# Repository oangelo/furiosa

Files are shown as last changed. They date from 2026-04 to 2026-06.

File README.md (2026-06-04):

# Furiosa

Triciclo elétrico documentado em todos os detalhes.

## Especificações

| Item | Detalhe |
|---|---|
| Motor dianteiro | Hub motor Citycoco ~3 kW (sensorless FOC) |
| Motor traseiro | Motor com redução + diferencial (Hall) |
| Baterias | 2x 16S em paralelo: 8P (28Ah, BMS 100A) + 6P (21Ah, BMS 60A) |
| Células | EVE INR18650-35V (3500 mAh, 10.2A) |
| Controlador | 2x Flipsky FSESC 75200 (CAN bus) |
| Tensão | 60V nominal / 67.2V máx |
| Capacidade total | 49 Ah |
| Corrente máx. | ~140A contínuos / 100A prático (BMS menor) |
| Autonomia | _a definir_ |
| Velocidade máx. | _a definir_ |
| Peso total | _a definir_ |

## Estrutura do repositório

```
furiosa/
├── busbar/          # Sistema de conexão de alta amperagem
│   ├── busbar.md    # Documentação geral do sistema
│   └── bus-box/     # Caixa protetora da busbar
│       └── exports/ # Arquivos exportados (STEP, STL, etc.)
├── specs/           # Especificações técnicas detalhadas
├── maintenance/     # Histórico de manutenções e reparos
├── mods/            # Modificações e upgrades realizados
└── media/           # Fotos, vídeos e imagens
```

## Documentação

- [Sistema Busbar](busbar/)
- [Especificações Técnicas](specs/)
- [Histórico de Manutenção](maintenance/)
- [Modificações e Upgrades](mods/)
- [Mídia](media/)

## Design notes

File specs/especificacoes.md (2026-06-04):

# Especificações Técnicas

Documentação técnica completa do triciclo elétrico Furiosa.

---

## Motores

### Motor Dianteiro (Hub Motor Citycoco)

| Parâmetro | Valor |
|---|---|
| Tipo | Hub motor (roda dianteira) |
| Potência nominal | ~3 kW |
| Topologia | SPM (Surface Permanent Magnet) |
| Saliência magnética | Lq−Ld ≈ 6.41 µH (~6.6%) |
| Indutância | L = 97.31 µH |
| Flux linkage | 16.4 mWb (−10% do detectado) |
| Construção | Shaft fixo, roda gira em torno do eixo |

**Status do sensor Hall:**
- Hall 3: **Falha confirmada** (cabo partido na entrada do axle ou sensor defeituoso)
- Diagnóstico: duty cycle desequilibrado + glitches no plot `hall_analyze`

**Modo de operação:** Sensorless (FOC observer)

**HFI:** Testado e descartado — motor SPM não tem saliência suficiente, plot sem padrão senoidal

**Preset:** Heavy Inertial Load
- Openloop Lock Time: 0.5s
- Ramp Time: 0.5s
- Time: 0.20s
- Current Boost: 5A
- Current Max: 20A
- ERPM: 1500

### Motor Traseiro (Redução + Diferencial)

| Parâmetro | Valor |
|---|---|
| Tipo | Motor com redução e diferencial mecânico |
| Sensor Hall | Funcionando normalmente |
| Flux linkage | 21.6 mWb (−5% do detectado de 22.75 mWb) |
| Observer Gain | 80% do detectado |
| Inércia rotacional | Maior que o dianteiro (devido à redução) |

---

## Controladores (VESC)

### 2x Flipsky/Makerbase FSESC 75200

| Parâmetro | Valor |
|---|---|
| Firmware | VESC 5.2+ (upgrade disponível) |
| Tensão | 14-84V (4-20S) |
| Corrente contínua | 50V/200A; 75V/150A |
| Corrente de pico | 300A (burst) / 400A (máximo) |
| BEC | 5V @ 1A |
| Modos | DC, BLDC, FOC (sinusoidal) |
| Comunicação | USB, CAN, UART, SPI, IIC |
| Sensores | ABI, HALL, AS5047, AS5048A |
| ERPM máximo | 150.000 |
| PCB | Alumínio (dissipação térmica) |

### Configuração CAN Bus

| VESC | CAN ID | Motor | Função |
|---|---|---|---|
| Dianteiro | 95 | Hub motor Citycoco | Tração dianteira |
| Traseiro | 90 | Motor com redução | Tração traseira |

### Parâmetros de Corrente (por VESC)

| Parâmetro | Valor |
|---|---|
| Battery Max | 40A |
| Battery Regen | −12A |
| Motor Max | 90A |
| Motor Brake | −30 a −50A |
| Absolute Max | 150A |

### Controle

- **App:** ADC (throttle de punho)
- **Ré:** Botão no pino ADC (não PPM)
- **Controle:** Mestre (dianteiro) → CAN → Escravo (traseiro)

### Brake Chopper Externo

| Parâmetro | Valor |
|---|---|
| Comparador | LM393 |
| MOSFET | IRFP450 |
| Resistor de carga | 10Ω 100W |
| Função | Dissipar energia da frenagem regenerativa |

---

## Baterias

Duas baterias 16S ligadas em paralelo via busbar.

### Bateria 1 — 16S8P

| Parâmetro | Valor |
|---|---|
| Configuração | 16S8P |
| Capacidade | 28 Ah (3500 mAh × 8P) |
| Corrente máxima contínua | ~80A (10.2A/célula × 8P) |
| BMS | Daly Smart BMS 100A 16S |

### Bateria 2 — 16S6P

| Parâmetro | Valor |
|---|---|
| Configuração | 16S6P |
| Capacidade | 21 Ah (3500 mAh × 6P) |
| Corrente máxima contínua | ~60A (10.2A/célula × 6P) |
| BMS | Daly Smart BMS 60A 16S |

### Pack Combinado (Paralelo)

| Parâmetro | Valor |
|---|---|
| Configuração | 16S(8P+6P) = 16S14P |
| Tensão nominal | 60V |
| Tensão máxima | 67.2V (4.2V/célula) |
| Tensão mínima | 48.0V (3.0V/célula) |
| Capacidade total | 49 Ah |
| Corrente máxima contínua | ~140A |
| Corrente prática limite | 100A (limitado pelo BMS menor) |

### Células — EVE INR18650-35V

| Parâmetro | Valor |
|---|---|
| Química | NCM (Li-ion) |
| Tensão nominal | 3.65V |
| Capacidade nominal | 3500 mAh |
| Descarga contínua máx | 10.2A |
| Descarga de pico | 20A |
| Tensão carga máx | 4.2V |
| Tensão corte descarga | 2.5V |
| Peso | ~48g |
| Dimensões | 18.3mm × 65.0mm |

### BMS — Daly Smart BMS

| Parâmetro | Bateria 1 | Bateria 2 |
|---|---|---|
| Corrente contínua | 100A | 60A |
| Balanço | Passivo | Passivo |
| Comunicação | WiFi + CAN + Bluetooth | WiFi + CAN + Bluetooth |
| Monitoramento | App mobile "Smart BMS" | App mobile "Smart BMS" |

### Voltage Cutoffs (16S)

| Parâmetro | Valor | Por célula |
|---|---|---|
| Start (soft) | 51.20V | 3.20V |
| End (hard) | 48.00V | 3.00V |

### Construção

- Montagem DIY
- Células 18650 com solda de níquel
- Caixa metálica
- BMS com antena WiFi externa
- Termistores para monitoramento de temperatura

### Histórico de Problemas

- Queima de tira de níquel (corrente excessiva)
- Substituição de células em algum ponto
- BMS original queimou MOSFET de descarga → substituído pelo Daly 100A

---

## Proteção

### Fusíveis — Spintend Physical Fuse v01

2 unidades instaladas, uma por VESC, na linha positiva entre busbar e controlador.

| Parâmetro | Valor |
|---|---|
| Modelo | Spintend Physical Fuse v01 by Hohn |
| Configuração por unidade | 2× 60A em paralelo = 120A |
| Tensão máxima | 100V |
| Conectores | Amass XT90PW (macho/fêmea) |
| Curva de disparo (120A) | 100% In: >4h / 200% In: <60s |
| Posição | Linha positiva, entre busbar e VESC |

Ver documentação completa: [Sistema de Liga/Desliga](sistema-ligadesliga.md)

---

## Distribuição de Potência

| Componente | Função |
|---|---|
| Copper busbar | Ponto central de distribuição |
| Parafusos inox M6 | Conexão dos cabos |
| Caixa protetora (bus box) | Isolamento e proteção |
| Fusíveis Spintend 120A | Proteção por VESC (sobrecarga/curto) |

Ver documentação completa: [Sistema Busbar](../busbar/busbar.md)

---

## Sistema de Liga/Desliga

| Componente | Especificação |
|---|---|
| Relé principal | 12V, 200A |
| Conversor DC-DC | 20-90V → 12V |
| Chave switch | ON/OFF |
| Botão momentâneo | NO |
| Resistor pré-carga | Desconhecido (em paralelo com relé) |

Ver documentação completa: [Sistema de Liga/Desliga](sistema-ligadesliga.md)

---

## Transmissão

- **Dianteira:** Direta (hub motor)
- **Traseira:** Redução mecânica com diferencial

## Freios

- **Dianteiro:** _a definir_
- **Traseiro:** _a definir_

## Rodas / Pneus

- **Dianteira:** _a definir_
- **Traseiras:** _a definir_

## Dimensões e Peso

- **Comprimento:** _a definir_
- **Largura:** _a definir_
- **Altura:** _a definir_
- **Peso total:** _a definir_

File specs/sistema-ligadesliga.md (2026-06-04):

# Sistema de Liga/Desliga — Furiosa

## O Problema da Faísca

Os controladores VESC possuem capacitores de entrada grandes (~1000µF cada, ~2000µF total no sistema). Quando a bateria é conectada diretamente a capacitores descarregados, a diferença de potencial é máxima e a corrente de surto é limitada apenas pela resistência interna dos capacitores e da fiação — praticamente um curto-circuito momentâneo.

**Corrente de surto estimada:**
```
I = V / R_esr
I = 60V / ~0.05Ω = ~1200A (pico teórico)
```

Na prática a corrente é menor (limitada pela indutância e resistência dos cabos), mas o suficiente para:

- **Arco elétrico** no momento da conexão — degrada conectores e terminais
- **Vaporização de material** nos contatos —Connectores XT90 são projetados para 90A contínuos, não para picos de centenas de ampères
- **Risco de queimadura** se o conector estiver na mão
- **Danos ao BMS** — o surto passa pelo BMS antes de chegar aos capacitores

O problema é idêntico ao de ligar uma chave em um banco de capacitores — sempre que a tensão do capacitor é muito diferente da tensão da fonte, haverá um transiente de corrente proporcional à diferença.

## Anti-Spark Switches Comerciais

Existem switches anti-spark dedicados que resolvem o problema:

- **Flipsky Anti-Spark Switch** (~R$ 200-300)
- **MakerX Anti-Spark Switch** (~R$ 150-250)
- **Vedder Anti-Spark Switch** (open-source, ~R$ 100 em componentes)

Funcionam com um MOSFET que faz a pré-carga gradualmente e depois liga completamente. São compactos e plug-and-play.

**Problemas:**
- Preço elevado para o que fazem
- Limitados em corrente (tipicamente 100-200A)
- Componente adicional que pode falhar
- Difícil reposição no Brasil

## Solução Barata: Pré-Carga com Resistor

A ideia é simples: em vez de conectar a bateria diretamente aos capacitores, conectar primeiro através de um resistor que limita a corrente a um valor seguro. Depois que os capacitores carregam, curto-circuitar o resistor para operação normal.

**Cálculo da corrente de pré-carga:**
```
Com R = 15Ω:
I_inicial = 60V / 15Ω = 4A
P_inicial = 60V × 4A = 240W (por frações de segundo)
```

**Tempo de carga:**
```
τ = R × C = 15Ω × 0.002F = 0.03s
5τ (carga completa) = 0.15s
```

Os capacitores carregam em ~150ms — praticamente instantâneo para um ser humano. Depois disso, a tensão nos capacitores iguala a da bateria e não há mais diferença de potencial significativa.

**Componentes mínimos:**
- Resistor de 15Ω, 50W — suporta o pico de 240W por 150ms sem problemas
- Um meio de curto-circuitar o resistor após a carga (relé, chave manual, etc.)

---

## Sistema Atual

### Componentes Instalados

| Componente | Especificação |
|---|---|
| Relé principal | 12V, 200A |
| Conversor DC-DC | 20-90V → 12V |
| Resistor de pré-carga | Valor desconhecido (instalado em paralelo com o relé) |
| Chave switch | ON/OFF |
| Botão momentâneo | NO (normalmente aberto) |
| Fusíveis (2×) | Spintend Physical Fuse v01, 120A cada (2× 60A paralelo), 100V |

### Como Funciona

```
                         ┌─────────────────┐
  Bateria 60V ──────────┤ Resistor         ├───────── [Fusível 120A] ──► VESC dianteiro
              │          └─────────────────┘              │
              │              │                            │
              │    ┌─────────┴─────────┐         [Fusível 120A] ──► VESC traseiro
              └────┤ Relé 200A         ├─────────┘
                   │ (N.O.)            │
                   └───────┬───────────┘
                           │
                     bobina 12V
                           │
              ┌────────────┴────────────┐
              │                         │
        Chave ON/OFF              Botão N.O.
              │                    (momentâneo)
              │                         │
              └─────┬───────────────────┘
                    │
             Conversor DC-DC
              (60V → 12V)
                    │
                  GND
```
                        ┌─────────────────┐
  Bateria 60V ──────────┤ Resistor         ├──── VESCs (+)
              │          └─────────────────┘     │
              │              │                    │
              │    ┌─────────┴─────────┐         │
              └────┤ Relé 200A         ├─────────┘
                   │ (N.O.)            │
                   └───────┬───────────┘
                           │
                     bobina 12V
                           │
              ┌────────────┴────────────┐
              │                         │
        Chave ON/OFF              Botão N.O.
              │                    (momentâneo)
              │                         │
              └─────┬───────────────────┘
                    │
             Conversor DC-DC
              (60V → 12V)
                    │
                  GND
```

**Para ligar:**

1. Chave → ON
2. Corrente flui pelo resistor → carrega capacitores dos VESCs (sem faísca)
3. Conversor DC-DC gera 12V → energiza bobina do relé
4. Relé fecha → curto-circuita o resistor → conexão direta bateria↔VESCs
5. Sistema operacional

**Para desligar:**

1. Pressionar botão momentâneo → corta alimentação da bobina do relé
2. Relé abre → sistema desligado
3. A chave ON/OFF sozinha **não desliga** o sistema

### Problemas do Sistema Atual

1. **Resistor permanentemente no circuito** — embora a maioria da corrente passe pelo relé (resistência ~mΩ), o resistor em paralelo dissipa energia continuamente quando o relé está fechado
2. **Sequência de desligamento confusa** — a chave liga mas não desliga, é necessário usar o botão
3. **Se o botão falhar, não há como desligar** — a não ser desconectar a bateria
4. **Sem indicador visual** — impossível saber se o sistema está ligado ou desligado sem medição

---

## Melhorias Possíveis

### Opção A: Dois Relés (Pré-Carga Dedicada)

Adicionar um segundo relé (automotivo 12V 40A, ~R$ 15-25) dedicado exclusivamente à pré-carga. O resistor só fica no circuito durante os ~150ms de carga.

**Esquema proposto:**
```
  Bateria 60V ──────┬──────────────────────────────── VESCs (+)
                    │                                    │
          ┌─────────┴──────────┐                         │
          │ Relé Pré-Carga 40A ├──── Resistor 15Ω 50W ───┤
          │ (N.O.)             │                         │
          └─────────┬──────────┘                         │
                    │                                    │
          ┌─────────┴──────────┐                         │
          │ Relé Principal 200A ├────────────────────────┘
          │ (N.O.)             │
          └─────────┬──────────┘
                    │
              bobinas 12V
```

**Lógica de operação:**
1. Chave ON → pressiona botão → relé de pré-carga liga → capacitores carregam via resistor
2. Relé principal liga (manualmente ou com delay) → curto-circuita resistor
3. Solta botão → relé de pré-carga desliga → resistor fora do circuito
4. Relé principal permanece ligado (auto-retenção)
5. Chave OFF → corta alimentação → relé principal desliga → sistema off

**Vantagens:**
- Resistor fora do circuito durante operação normal
- Desligamento simples: basta a chave OFF
- Componentes baratos e fáceis de encontrar

**Desvantagens:**
- Mais fiação e complexidade
- Dois relés para gerenciar
- Necessita lógica de auto-retenção no relé principal

### Opção B: Chave Seletora (Manual)

Substituir o sistema de relés por uma chave seletora de 3 posições: OFF → PRÉ-CARGA → ON.

Na posição PRÉ-CARGA, a corrente passa pelo resistor. Na posição ON, a corrente passa direto. Sem eletrônica, sem relés.

**Vantagens:**
- Extremamente simples e robusto
- Sem eletrônica que pode falhar
- Operação intuitiva

**Desvantagens:**
- Precisa de uma chave de alta corrente (carregadora de bateria ou similar)
- Operação manual em dois passos
- Difícil encontrar chave adequada para 100A+ no Brasil

### Opção C: Anti-Spark Switch Comercial

Substituir todo o sistema por um anti-spark switch dedicado (ex: Flipsky, ~R$ 200-300).

**Vantagens:**
- Plug-and-play, sem projeto
- Compacto
- Pré-carga automática via MOSFET

**Desvantagens:**
- Caro
- Limitado em corrente
- Se queimar, é componente único sem reposição fácil

### Opção D: MOSFET com Pré-Carga (DIY)

Circuito com MOSFET de alta corrente (ex: IRFP4468) controlado por um RC para ramp de gate lenta, fazendo a pré-carga automaticamente.

**Vantagens:**
- Sem partes mecânicas (sem desgaste de contatos)
- Pré-carga automática e controlada
- Barato em componentes (~R$ 30-50)

**Desvantagens:**
- Complexidade eletrônica significativa
- Necessita dissipador grande
- Falha em MOSFET pode ser perigosa (curto permanente)
- Exige conhecimento de eletrônica de potência para projetar

### Comparação

| Critério | A: 2 Relés | B: Chave Seletora | C: Comercial | D: MOSFET DIY |
|----------|------------|-------------------|--------------|----------------|
| Custo | ~R$ 50 | ~R$ 30-80 | ~R$ 200-300 | ~R$ 30-50 |
| Complexidade | Média | Baixa | Baixa | Alta |
| Robustez | Alta | Muito alta | Média | Baixa |
| Desligamento simples | Sim | Sim | Sim | Sim |
| Reposição fácil | Sim | Sim | Não | Parcial |
| Sem resistor permanente | Sim | Sim | N/A | N/A |

---

## Referências

- [Especificações Técnicas Gerais](especificacoes.md)
- [Sistema Busbar](../busbar/busbar.md)

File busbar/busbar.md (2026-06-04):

# Sistema Busbar - Conexão de Alta Amperagem

## Descrição

Sistema de conexão elétrica de alta potência para o triciclo elétrico Furiosa. 
Consiste em uma barra de cobre com múltiplos terminais para conexão dos cabos de 
alimentação, protegida por uma caixa impressa em 3D.

## Componentes

### 1. Barra de Cobre

| Parâmetro | Valor |
|---|---|
| Material | Cobre eletrolítico |
| Espessura | 5 mm |
| Largura | 25 mm |
| Comprimento | ~50 mm (por segmento) |
| Quantidade | 3 segmentos |
| Acabamento | Furos e rosca M6 |

**Observações:**
- Barra cortada em pedaços de pouco menos de 50mm
- Furos roscados para fixação dos cabos
- Cobre por excelente condutividade elétrica

### 2. Fixação - Parafusos

| Parâmetro | Valor |
|---|---|
| Material | Aço inox |
| Tamanho | M6 |
| Quantidade | 3 por barra |
| Acabamento | Rosca completa |

**Por que inox?**
- Resistência à oxidação e corrosão
- Manutenção da condutividade ao longo do tempo
- Ideal para ambiente com vibração (veículo elétrico)

### 3. Porcas e Arruelas

| Componente | Especificação |
|---|---|
| Porcas | M6 auto-travantes com nylon |
| Arruelas | Inox M6 |

**Por que porcas com nylon?**
- Trava química que impede afrouxamento
- Resistente à vibração do veículo
- Não requer manutenção periódica de aperto

### 4. Caixa Protetora (Bus Box)

| Parâmetro | Valor |
|---|---|
| Material | _a definir_ (impressão 3D / usinagem) |
| Função | Proteção e isolamento da barra |
| Acesso | Tampa com parafusos |
| Status | Em desenvolvimento |

## Funcionamento

```
[ Bateria ] ──► [ Cabo ] ──► [ Busbar ] ──► [ Cabo ] ──► [ Controlador ]
                                    │
                                    ├──► [ Cabo ] ──► [ Motor ]
                                    │
                                    └──► [ Cabo ] ──► [ Acessórios ]
```

A barra de cobre serve como ponto central de distribuição da corrente, permitindo
múltiplas conexões de forma organizada e segura.

## Especificações Elétricas

| Parâmetro | Valor |
|---|---|
| Tensão nominal | 60V (16S Li-ion) |
| Tensão máxima | 67.2V |
| Corrente máxima | ~80A contínuos (limite das células) |
| Corrente prática | até 100A |
| Seção do cabo | _a definir_ |
| Tipo de conexão | Parafuso M6 com terminal olhal |

## Materiais Necessários

- [x] Barra de cobre 5x25mm
- [x] Parafusos inox M6 (9 unidades - 3 por barra)
- [x] Porcas auto-travantes M6 com nylon (9 unidades)
- [x] Arruelas inox M6 (9 unidades)
- [ ] Caixa protetora (em desenvolvimento)
- [ ] Cabos de alta corrente com terminais olhal M6

## Status do Projeto

**Em desenvolvimento (WIP)**

- [x] Definição da barra de cobre
- [x] Definição dos parafusos e fixações
- [x] Corte e preparação da barra
- [ ] Finalização da caixa protetora
- [ ] Testes de montagem
- [ ] Testes elétricos sob carga

## Notas de Desenvolvimento

- Barra de cobre cortada manualmente em segmentos de ~50mm
- Furos roscados M6 para fixação segura dos cabos
- Uso de inox em toda a fixação para evitar corrosão galvânica
- Porcas com nylon essenciais para ambiente com vibração

## Próximos Passos

1. Finalizar modelo 3D da caixa protetora
2. Imprimir/testar caixa
3. Definir seção e tipo dos cabos de conexão
4. Realizar testes de carga
5. Verificar aquecimento sob operação

## Arquivos Relacionados

- `busbar/bus-box/bus-box.FCStd` - Modelo FreeCAD da caixa (em desenvolvimento)
- `busbar/bus-box/exports/` - Arquivos exportados (STEP, STL, etc.)

## Referências

- [Especificações Técnicas](../specs/)
- [Modificações e Upgrades](../mods/)

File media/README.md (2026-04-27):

# Fotos

Adicione as fotos do triciclo nesta pasta.

Organize em subpastas se necessário, por exemplo:

- `fotos/gerais/` - Fotos gerais do triciclo
- `fotos/detalhes/` - Detalhes de componentes
- `fotos/modificacoes/` - Antes e depois de modificações

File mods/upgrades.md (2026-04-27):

# Modificações e Upgrades

Registro de todas as modificações e upgrades realizados.

| Data | Modificação | Motivo | Custo (R$) |
|---|---|---|---|
| _exemplo_ | _descrição da modificação_ | _motivo_ | _valor_ |

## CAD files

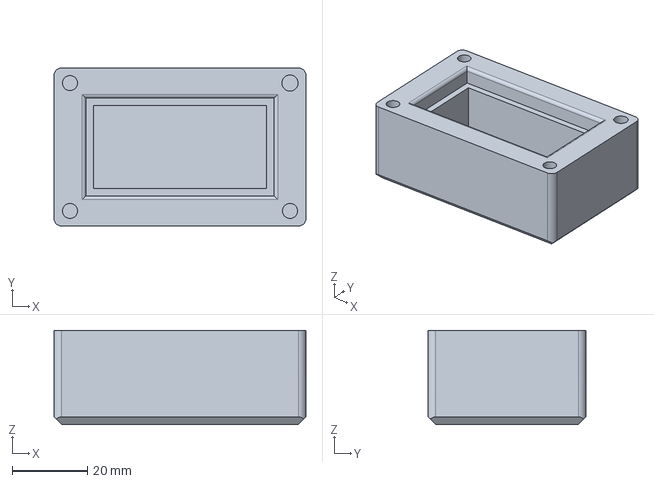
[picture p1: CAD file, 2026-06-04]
busbar/bus-box/bus-box.FCStd
67.0 x 42.0 x 25.0 mm

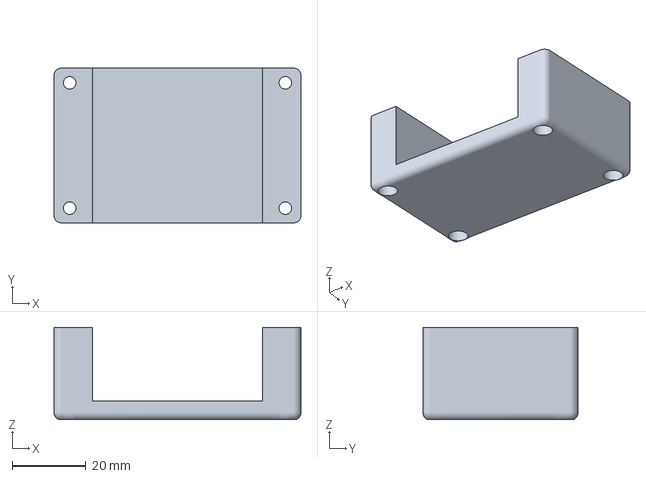
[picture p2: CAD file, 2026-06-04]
busbar/bus-box/exports/bus-box-tampa.3mf
67.0 x 42.0 x 25.0 mm

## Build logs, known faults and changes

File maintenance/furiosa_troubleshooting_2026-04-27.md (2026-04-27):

# Resumo da sessão de troubleshooting da Furiosa

## Ponto de partida

Você queria controlar o motor pelo VESC Tool e tinha um VESC dianteiro que não funcionava enquanto o traseiro rodava perfeitamente.

## Sequência do diagnóstico

**1. Controle pelo VESC Tool e interferência do ADC.** Descobrimos que o app ADC ativo sobrescreve os comandos da interface (setas, botões play/pause), mesmo via USB/CAN — bug conhecido no firmware. Solução: mudar temporariamente "App to Use" para "No App" durante testes pela interface. Você desativou o ADC e conseguiu testar livremente.

**2. Problema do VESC dianteiro — hipótese inicial: mosfet queimado?** O traseiro funcionava, o dianteiro não. Eu te dei o procedimento de teste de mosfets pelos fios de fase com multímetro em modo diodo, mas ressaltei que a 75200 tem 6 mosfets paralelos por fase, dificultando diagnóstico de mosfet individual.

**3. Refinamento do diagnóstico — não era mosfet.** Você descreveu o sintoma certo: "vibra loucamente mas não gira, sendo que na detection gira perfeitamente". Esse padrão exclui mosfet — detection roda em open-loop, então se uma fase estivesse comprometida, falharia ali. O problema estava no closed-loop (observer ou sensor).

**4. Investigação do hall sensor.** A tabela de hall do dianteiro estava numericamente correta (deltas de ~33 unidades, sequência monotônica), mas o motor vibrava com hall ativo. Você fez `hall_analyze` e o plot mostrou:
- Hall 3 com duty cycle absurdamente desbalanceado (ficava em 1 quase o tempo todo)
- Glitches impossíveis nos canais individuais
- Sequência caótica do "Combined"

Diagnóstico: hall sensor com problema elétrico — possivelmente sensor 3 com defeito, ou cabo de hall com mau contato/quebrado na entrada do eixo do hub motor.

**5. Tentativa de HFI como alternativa.** Medimos a saliência do motor: **L = 97,31 µH, Lq-Ld = 6,41 µH (~6,6%)**. Saliência marginal, típica de hub motor SPM (ímãs colados na superfície). Você ativou HFI e o plot mostrou ruído quase uniforme sem padrão senoidal — tracking inviável. **HFI descartado** para esse motor.

**6. Decisão: sensorless puro.** Você confirmou que sem hall, em modo sensorless, o motor da Furiosa funciona super forte. Diagnóstico fechado: VESC e motor estão íntegros, problema isolado ao hall sensor do dianteiro (mas você decidiu não abrir o motor).

**7. Tuning do open-loop pra melhorar a partida.** Aplicou o preset "Heavy Inertial Load" e ajustou parâmetros. Configuração final aceita:
- Openloop ERPM = 1500
- Openloop Hysteresis = 0,15 S
- Openloop Lock Time = 0,5 S
- Openloop Ramp Time = 0,5 S
- Openloop Time = 0,20 S
- Openloop Current Boost = 5 A
- Openloop Current Max = 20 A

**8. Problema do botão de ré.** O botão de ré não funcionava no modo "Current Reverse ADC2 Brake Button" — bug conhecido no firmware. Como teu manete é unidirecional (estilo moto), você precisava escolher entre regen variável e ré.

**9. Resolução final do botão de ré.** O problema real era o pino: você estava com **App to Use = "ADC and UART"** mas o botão estava conectado no pino que correspondia ao modo "ADC". Mudou para "ADC" puro e funcionou.

## Estado final da Furiosa

- **VESC traseiro:** modo Hall, funcionando perfeitamente.
- **VESC dianteiro:** modo Sensorless com tuning Heavy Inertial Load, partida aceitável.
- **Controle:** ADC com botão de ré funcionando, App to Use = "ADC".
- **Bateria 16S8P:** OK.
- **Pendência futura (sem urgência):** abrir o cubo do dianteiro um dia pra investigar o cabo de hall na entrada do eixo (ponto clássico de quebra por flexão). Se o sensor 3 estiver morto, troca por SS41 ou A3144 latching.

## Nota sobre o setup de conexão usado no diagnóstico

Durante esta sessão, o VESC Tool estava rodando no PC conectado via IP bridge a um celular, que por sua vez conectava ao VESC por Bluetooth. Segundo relatos no [fórum pev.dev](https://pev.dev/t/diagnosing-hall-sensors/1795/3), essa cadeia de conexão (Bluetooth + bridge) pode introduzir latência e ruído que comprometem ferramentas de diagnóstico como `hall_analyze`. O `hall_analyze` não rodou corretamente neste setup — possivelmente seria necessário conectar o cabo USB direto ao VESC para resultados confiáveis. Isso não invalida o diagnóstico de hall com defeito (os sintomas de vibração e os plots com glitches são consistentes), mas o resultado do `hall_analyze` deveria ser confirmado com conexão direta antes de conclusões definitivas sobre qual sensor está falhando.

## Aprendizados técnicos da sessão

- ADC ativo bloqueia controle pela interface do VESC Tool (mudar pra "No App" pra testar).
- Detection rodando bem + motor vibrando no controle = problema de sensor/observer, não de mosfet.
- Tabela de hall correta numericamente não garante hall funcional sob carga — sinal pode estar sujo, com glitches, ou intermitente.
- HFI exige saliência ≥15% pra funcionar bem; hub motor SPM raramente atende.
- O pino do botão de reverse depende do "App to Use" — erro comum trocar entre "ADC" e "ADC and UART" sem religar o botão no pino correto.
- Bug conhecido: "Current Reverse ADC2 Brake Button" ignora o botão de reverse no firmware atual.

## Para guardar

Salva o XML da config final do dianteiro como `furiosa_dianteiro_sensorless_2026-04-27.xml` e do traseiro como `furiosa_traseiro_hall_2026-04-27.xml`. Da próxima vez que mexer ou atualizar firmware, você tem o ponto de partida bom guardado.

Boa pilotada na Furiosa. 🏍️

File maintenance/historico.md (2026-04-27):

# Histórico de Manutenção

Registro de todas as manutenções realizadas na Furiosa.

| Data | Tipo | Descrição | Custo (R$) |
|---|---|---|---|
| abr/2026 | corretiva | Diagnóstico completo dos VESCs pós-desconexão de bateria. Re-flash firmware 6.06, investigação CAN, validação Flipsky 75200 Alu (operacional), Makerbase 75200 V2 OLD (CAN forwarding pendente). Ver [diagnóstico completo](furiosa_vesc_diagnostico_2026-04.md). | — |
| 27/abr/2026 | corretiva | Sessão de troubleshooting: hall sensor dianteiro com defeito (sensor 3), HFI descartado (saliência 6,6%), dianteiro migrado para sensorless com tuning Heavy Inertial Load. Botão de ré resolvido (App to Use = ADC). Ver [resumo completo](furiosa_troubleshooting_2026-04-27.md). | — |

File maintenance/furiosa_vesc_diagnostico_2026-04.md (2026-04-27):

# Furiosa — Diagnóstico e Configuração dos VESCs (abr/2026)

## Resumo executivo

Setup dual VESC do triciclo elétrico Furiosa após incidente de desconexão súbita
de bateria durante operação. Documenta processo de re-flash de firmware,
investigação de problemas de comunicação CAN entre as duas placas, configuração
master/slave, e estado funcional final.

**Status atual:**

- **Flipsky FSESC 75200 Alu (motor traseiro IPM, ID 90)** — operacional.
  Sustenta 80A de phase current a 95% duty sem aquecimento anormal.
- **Makerbase MKSESC 75200 V2 OLD (hub dianteiro SPM, ID 95)** — detecção de
  motor funciona e gira a roda em teste isolado, mas **não está recebendo
  comandos ADC via CAN do master**. Causa raiz não confirmada.
- **Investigação pendente:** testar se Makerbase responde a ADC direto na placa
  (sem CAN forwarding) para isolar dano de hardware vs. configuração.

## Hardware

### Placa 1 — Hub dianteiro

- **Modelo:** Makerbase MKSESC 75200 V2 (revisão antiga, anterior a 15/nov/2023).
- **Compra:** abril/2023, loja oficial Makerbase, R$ 528,18.
- **Hwconf na firmware:** `MKSESC_75200_V2_OLD`.
- **Característica de hardware:** low-side current sensing, **sem phase shunts**
  reais, **sem suporte a phase filtering**. Phase filter ligado nesta revisão
  pode danificar o ESC.
- **VESC ID no CAN:** 95.

### Placa 2 — Motor traseiro

- **Modelo:** Flipsky FSESC 75200 Aluminum PCB (versão original, anterior a Pro V2.0).
- **Hwconf na firmware:** `FSESC_75_200_ALU`.
- **Característica de hardware:** mesma topologia low-side, sem phase filter de
  hardware.
- **VESC ID no CAN:** 90.

### Motores

Resultados da Detection (firmware 6.06):

| Parâmetro | Hub dianteiro (Citycoco) | Motor traseiro (com diferencial) |
|---|---|---|
| Motor Current detectado | 94.48 A | 67.64 A |
| Motor R | 29.90 mΩ | 58.30 mΩ |
| Motor L | 96.32 µH | 161.15 µH |
| Motor Lq–Ld | 8.21 µH | **76.42 µH** |
| Motor Flux Linkage (λ) | 18.20 mWb | 22.75 mWb |
| Sensores | Hall | Hall |

**Interpretação:**

- **Hub dianteiro:** SPM clássico (Surface Permanent Magnet). Lq–Ld baixo
  indica rotor isotrópico. Sem reluctance torque significativo. MTPA dará
  ganho marginal.
- **Motor traseiro:** **IPM** (Interior Permanent Magnet) confirmado pela
  saliência alta (Lq–Ld = 76 µH). Tem reluctance torque disponível.
  **MTPA bem configurado pode trazer 10–15% de torque adicional por amp.**

## Bateria

- 16s8p EVE INR18650-35V.
- Histórico anterior: reparo de strip de níquel queimado (positivo).
- **Incidente recente:** desconexão súbita durante operação. Causa raiz da
  desconexão não documentada (BMS, conector, célula?).
- Implicação para os VESCs: spike de sobretensão de back-EMF + capacitância
  parasita pode ter estressado MOSFETs, capacitores eletrolíticos e
  transceivers CAN das duas placas.

## Histórico de firmware

### Origem do problema com firmware

Estas placas (Makerbase 75200 V2 e Flipsky 75200 Alu) foram lançadas com
firmware proprietária dos fabricantes que reportava `Hw: 75_300_R2` (incorreto).
Medições de corrente eram ruidosas, recursos como field weakening estavam
indisponíveis ou bugados. Não havia opção de update via VESC Tool oficial.

### Solução comunitária (2022)

- **jaykup** (esk8.news forum) compilou firmwares customizadas com hwconfs
  corretos (`FSESC_75_200_ALU`, `MKSESC_75_200_V2_OLD`) e disponibilizou
  como `.bin` para upload manual via VESC Tool.
- **casainho** (jan/2024) lançou release `VESCs_fix_noisy_currents-firmware_6.02`
  com filtro de corrente em software, melhorando significativamente a leitura
  ruidosa dos shunts low-side.

### Estado atual (2026)

- Os hwconfs `MKSESC_75_200_V2_OLD`, `MKSESC_75_200_V2`, `FSESC_75_200_ALU`
  estão **mergeados no upstream do Vedder** (`vedderb/bldc`) há tempos.
- Firmware é distribuída via VESC Tool em todas as releases atuais (6.06).
- O "manual change" descrito no tutorial original do jaykup hoje significa
  apenas **selecionar o hwconf correto uma vez** via "Show non-default
  firmwares", não baixar `.bin` de fórum.

### Fluxo de update aplicado

Para cada placa, uma única vez:

1. VESC Tool 6.06, conexão USB direta na placa.
2. Estado inicial: `Hw: 75_300_R2` (errado, mas é o que a fábrica configura).
3. **Firmware → Bootloader → Upload** (genérico).
4. **Firmware → Included Files → "Show non-default firmwares"**.
5. Seleciona o hwconf correto:
   - Makerbase (compra anterior a 15/nov/2023): `MKSESC_75200_V2_OLD`
   - Flipsky 75200 Alu (versão original): `FSESC_75_200_ALU`
6. Upload, reboot.
7. Confirma `HW_NAME` correto no Firmware tab após reboot.

A partir desse ponto, updates de versão (6.06 → 6.07 → ...) acontecem como
update normal — sem mais intervenção manual de hwconf.

### Critério crucial: phase filter

**Ambas as placas (Makerbase V2 OLD e Flipsky 75200 Alu) DEVEM ter
`Enable Phase Filters = False`** em Motor Settings → FOC → Filters.

Razão: nenhuma das duas tem phase shunts reais. Phase filtering em hardware
sem phase sensing é a queixa estrutural do pessoal técnico do esk8 forum
("phase filter joke"). Ligar pode danificar o ESC em ambas as gerações.

A Makerbase V2 nova (pós-Nov/2023) adicionou hardware para phase filter, mas
mantendo low-side sensing. A recomendação da comunidade veterana continua
sendo manter phase filter desligado mesmo na V2 nova.

## Configuração dual VESC via CAN

### Topologia adotada

- **Master:** Flipsky 75200 Alu (ID 90, motor traseiro). Lê ADC do throttle e
  replica comando via CAN para o slave.
- **Slave:** Makerbase 75200 V2 OLD (ID 95, hub dianteiro). Sem app de input
  ativo, apenas obedece comandos CAN do master.

### Configuração esperada — Master (Flipsky)

| Tab | Parâmetro | Valor |
|-----|---|---|
| App Settings → General | App to Use | ADC |
| App Settings → General → CAN | Controller ID | 90 |
| App Settings → General → CAN | CAN Baud Rate | 500k |
| App Settings → General → CAN | CAN Mode | VESC |
| App Settings → General → CAN | Send Status Over CAN | All |
| App Settings → General → CAN | Send CAN Status Rate Hz | 50 |
| App Settings → ADC → General | **Multiple ESCs Over CAN** | **TRUE** |
| App Settings → ADC → General | Control Type | (conforme throttle físico) |
| App Settings → ADC → General | Use Filter | True |

**Crítico:** o toggle **"Multiple ESCs Over CAN"** fica dentro da aba do app
ADC, **não** na aba CAN geral. Erro comum é configurar somente na aba CAN
geral e o forwarding do input não acontecer.

### Configuração esperada — Slave (Makerbase)

| Tab | Parâmetro | Valor |
|-----|---|---|
| App Settings → General | App to Use | **No App** |
| App Settings → General → CAN | Controller ID | 95 |
| App Settings → General → CAN | CAN Baud Rate | 500k |
| App Settings → General → CAN | CAN Mode | VESC |
| App Settings → General → CAN | Send Status Over CAN | All |

Slave não precisa de input próprio configurado. Status continua sendo enviado
via CAN para que o master possa monitorar (RT data, traction control).

### Tunagem inicial recomendada (não totalmente aplicada)

| Parâmetro | Hub Citycoco (ID 95) | IPM Traseiro (ID 90) |
|---|---|---|
| Flux Linkage detectado | 18.20 mWb | 22.75 mWb |
| Flux Linkage inicial sugerido | 16.4 mWb (–10%) | 21.6 mWb (–5%) |
| Observer Gain | 50% do detectado | 80% do detectado |
| Inductance (L) | manter detectado | manter detectado |
| Resistance (R) | manter detectado | manter detectado |
| MTPA | habilitar (ganho marginal) | **habilitar (ganho real)** |
| Field Weakening | 10–15A inicial | 10–20A inicial |
| Phase Filter | **False** (obrigatório) | **False** (obrigatório) |
| Sensor Mode | Hybrid | Hybrid |
| Sensorless ERPM threshold | 2000–3000 | 2000–3000 |

### Limites de corrente sugeridos

Considerando bateria 16s8p EVE INR18650-35V (capacidade nominal de pico ao
redor de 280A teóricos, mas conservativo para vida útil ~160–200A):

Por VESC, ponto de partida:

- **Motor (phase) max:** 80A em cada.
- **Battery max:** 50A em cada VESC, totalizando 100A de pack draw.
- **Battery min (regen):** −20A em cada, totalizando −40A regen.

Subir gradualmente após validação térmica e estabilidade de controle.

## Eventos e diagnóstico (cronológico)

### Incidente — desconexão de bateria sob carga

Bateria desconectou subitamente durante operação no triciclo. Causa raiz
exata não documentada. Possíveis riscos para os VESCs:

1. **Voltage spike de back-EMF + indutância parasita** — pode exceder breakdown
   dos MOSFETs (HYG015N10NS1TA, 100V).
2. **Loop de regen sem destino** — corrente regenerativa sem bateria como sink,
   capacitor de barramento absorve tudo, possível overvoltage.
3. **Faísca no reconnect** — inrush current alto se bateria reconectou com
   motor ainda em movimento.

### Resultado da Detection pós-incidente

Detection bem-sucedida em ambas as placas (resultado documentado acima).
Isso confirma:

- MCU funcional em ambas.
- USB e CAN físico operacionais para discovery.
- Pelo menos um par de gate drivers funcional por placa.
- Current sensing funcional nas três fases (caso contrário R, L, λ não seriam
  medidos coerentemente).
- Sensores Hall lidos corretamente.

**Detection NÃO testa:** MOSFETs sob alta corrente sustentada, capacitores
sob stress térmico, gate drivers degradados, sensores de Vbus descalibrados,
trilhas de PCB parcialmente danificadas.

### Sintoma 1 — "trancos estranhos" durante movimentação

Hub dianteiro apresentou movimento aos trancos. Hipóteses levantadas
(em ordem de probabilidade):

1. Tabela de Hall sensors não detectada/recalibrada após mudanças.
2. Ordem de fases vs. ordem de Halls inconsistente.
3. Sensor Mode em Sensorless puro em vez de Hybrid.
4. Openloop ruim na partida.

**Não totalmente investigado** antes da próxima descoberta.

### Sintoma 2 — Makerbase "sumindo" no CAN

Slave Makerbase desapareceu do dropdown de VESCs no VESC Tool durante
investigação dos trancos.

**Causa raiz identificada:** as duas VESCs estavam configuradas com o
**mesmo Controller ID**. Em CAN bus, IDs duplicados causam colisão de
pacotes e o VESC Tool não consegue distinguir as placas.

**Ação:** alterado um dos IDs para tornar único (95 e 90).

### Sintoma 3 — Comando manual de current via teclado não responde

Após config de IDs, descoberto que ADC funciona normalmente (motor gira
suavemente movendo o throttle), mas comando manual de "set current" via
teclado/slider do VESC Tool não faz o motor girar mesmo com valores altos.

**Hipótese provável:** comandos manuais de "Set Current" via VESC Tool têm
**timeout interno de ~1 segundo** — se não reenviado dentro do timeout, o
controle volta para zero. Comandos via app (ADC) são contínuos por design.

**Hipótese secundária:** valores baixos (5–10A) podem estar abaixo do
threshold de atrito estático do hub motor parado, que precisa tipicamente
de 15–25A para iniciar rotação.

**Não-bloqueador para operação real** — ADC funcionando é o caminho
operacional desejado.

### Sintoma 4 (atual) — Slave Makerbase não responde a comandos via CAN forwarding

Estado atual após todas as configurações acima:

- Master (Flipsky) recebe ADC e gira motor traseiro normalmente.
- Slave (Makerbase) aparece no scan CAN, Detection roda com sucesso, motor
  gira em testes isolados.
- Quando master está acelerando via ADC, **slave permanece parado**.
- Não confirmado se Iq do slave está chegando a zero (comando não
  propagou) ou está com valor mas sem efeito (problema de execução
  no slave).

**Investigação pendente:**

1. Conectar ADC direto na Makerbase (sem CAN) para testar se input físico
   gira o motor isoladamente. Se sim → problema é específico de CAN
   forwarding. Se não → problema é mais profundo no slave.
2. Verificar Iq, Duty Cycle e Current Setpoint do slave em RT Data
   simultâneo enquanto master comanda.
3. Testar comando direto via terminal do master:
   `fwd_can 95 motor_current` (ou sintaxe equivalente).
4. Substituir cabo CAN por outro para descartar mau contato físico.
5. Medir resistência entre CAN_H e CAN_L com tudo desligado:
   - Esperado: ~60Ω (dois terminadores de 120Ω em paralelo).
   - 120Ω: faltou um terminador.
   - Infinito: faltam ambos.
6. Wipe Configuration completo das duas placas e reconfigurar do zero.

## Status operacional validado

### Flipsky 75200 Alu — APROVADO para operação

Teste de carga sustentado:

- Throttle aplicado via ADC.
- Sustentou **80A de phase current a 95% duty cycle**.
- **Sem aquecimento anormal**.
- **Sem fault** durante o teste.

Indica MOSFETs, gate drivers, current sensing e dissipação térmica em
condição operacional pós-incidente. Placa pode ser considerada saudável.

### Makerbase 75200 V2 OLD — STATUS PARCIAL

- Detection: OK.
- Motor gira em teste isolado (movimento mostrado).
- **Não responde a comandos do master via CAN forwarding** (causa raiz
  pendente).
- Saúde de hardware sob carga sustentada **não validada** (testes de carga
  progressiva não realizados isoladamente nesta placa).

## Próximos passos

### Curto prazo (diagnóstico)

1. **Conectar ADC direto na Makerbase** e testar se input físico gira o motor.
   Resultado isola se problema é só CAN forwarding ou mais profundo.
2. **RT Data simultâneo** das duas placas durante operação ADC do master.
   Olhar Iq, Duty Cycle, Current Setpoint do slave.
3. **Substituir cabo CAN** por cabo de teste novo.
4. **Multímetro** entre CAN_H e CAN_L (tudo desligado): esperado ~60Ω.
5. **Wipe + reconfigure** se nada acima resolver.

### Médio prazo (validação completa)

1. Teste de carga progressiva (20A → 40A → 60A → 80A) na Makerbase
   isoladamente, mesmo padrão validado na Flipsky.
2. Teste de regen estático (`foc_openloop 30 3000` seguido de
   `foc_openloop -20 3000`) em ambas para validar tolerância a regen
   pós-incidente.
3. Logging metr.at em trajeto curto real para detectar assimetrias
   (temperatura, corrente, RPM, regen).

### Longo prazo (decisão de upgrade)

Se confirmado dano persistente na Makerbase ou problema irreparável de CAN:

| Opção | Custo aprox. (BR) | Ganho real |
|---|---|---|
| MKSESC 75200 V2 OLD usado | ~R$ 400–500 | Lateral, mesmo problema potencial |
| MKSESC 75200 V2 nova (pós-Nov/2023) | ~R$ 600 | Marginal |
| **MKSESC 84200HP** (INA241, phase shunts reais) | **~R$ 700–1200** | **Significativo: resolve estruturalmente o ruído de current sensing** |
| Spintend UBOX V2 75V | ~R$ 700–1000 | Lateral |
| Trampa VESC 75/300 | R$ 2500+ | Excelente, overkill |

**Recomendação se for trocar:** Makerbase 84200HP. Resolve estruturalmente
o problema original de leitura de corrente que motivou todo o histórico
de firmware customizada (jaykup, casainho). Mantém compatibilidade de
tensão (84V = 16s full charge). Permite usar phase filter corretamente.
MTPA mais efetivo no motor traseiro IPM.

Decisão recomendada de escopo:

- Substituição de UMA placa (R$ ~900): mantém setup heterogêneo, requer
  tuning separado das duas.
- Substituição de AMBAS (R$ ~1800): setup simétrico, fácil de tunar,
  Makerbase V2 OLD e Flipsky Alu antigas viram peças para Maldita ou
  Gárgula.

## Observações técnicas relevantes

### Sobre a "vadicus strategy"

Para hub motors grandes que apresentam ABS overcurrent ou cogging em
baixa rotação, a abordagem documentada no esk8 forum recomenda:

- Reduzir Observer Gain para 30–50% do valor detectado.
- Reduzir Flux Linkage em 10–15% do detectado.
- Subir `Slow ABS Current Limit` para True (usa magnitude vetorial em vez
  de shunt individual, mais robusto a ruído).
- Aumentar `Max Absolute Current` 20–30% acima do `Motor Max` configurado.

### Sobre detection com dual VESC

**Sempre rodar Motor Detection com apenas uma VESC ativa por vez.**
Há relatos no fórum de placas danificadas por detection paralela em CAN
bus simultâneo. Desconectar fisicamente o motor da outra VESC durante
detection é a prática recomendada.

### Sobre CAN forwarding e timeout

Comandos enviados via CAN têm timeout de ~1 segundo no receptor. O master
deve enviar comandos em frequência maior que isso (50 Hz padrão).
Send CAN Status Rate baixo demais (1–5 Hz) causa o slave receber comando,
expirar, voltar a zero, receber próximo, expirar novamente — comportamento
"engata-larga" indistinguível de problema de hardware.

### Sobre IDs CAN duplicados

VESC Tool não detecta IDs duplicados de forma explícita. Sintoma é placa
"sumir" intermitentemente do dropdown ou comportamento errático no
forwarding. Sempre verificar manualmente que IDs são únicos quando
configurar dual ou multi-VESC.

## Referências

- Tópico original do jaykup no esk8.news:
  <https://forum.esk8.news/t/how-to-update-firmware-on-the-flipsky-75100-75200-foc-esc/61819>
- Release do casainho com filtro de corrente:
  <https://github.com/casainho/bldc/releases> (tag
  `VESCs_fix_noisy_currents-firmware_6.02`)
- Wiki da Makerbase (desatualizada, escrita em 2022):
  <https://github.com/makerbase-mks/VESC-MKS/wiki/Makerbase-VESC75-Series-Upgrade-Instructions>
- Hwconf MKSESC_75_200_V2_OLD no upstream do Vedder:
  <https://github.com/vedderb/bldc/blob/master/hwconf/makerbase/75_200_V2/hw_mksesc_75_200_v2_old.h>
- Archive de firmwares compiladas históricas:
  <https://github.com/vedderb/vesc_fw_archive>

---

*Documento gerado em abril/2026 como registro técnico do projeto Furiosa
para o repositório no GitHub.*

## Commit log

2026-04-27 Adiciona diagnóstico VESC abr/2026 e registra no histórico de manutenção
2026-04-27 Adiciona resumo da sessão de troubleshooting 27/abr/2026
2026-05-29 chore: renomear arquivo FreeCAD para usar hifens
    [caixa-conexao-alta-amperagem.FCStd]
2026-05-29 docs: adicionar documentacao da caixa de conexao de alta amperagem
2026-05-29 refactor: padronizar nomes de arquivos e pastas
    - Renomear pastas: fotos→media, manutencao→maintenance, modificacoes→mods
    - Renomear arquivos: caixa-conexao-alta-amperagem→bux-box
    - Atualizar README.md com nova estrutura
    [bux-box.FCStd]
2026-05-29 feat: atualizar modelo bux-box
    [bux-box.FCStd]
2026-06-01 fix: renomear bux-box para bus-box e atualizar modelo
    [bus-box.FCStd, bux-box.FCStd]
2026-06-01 chore: adicionar .gitignore para ignorar backups do FreeCAD e arquivos STEP
2026-06-01 feat: adicionar preview STL e informacoes do modelo bus-box
    [bus-box-preview.stl]
2026-06-01 feat: adicionar script e arquivos de desenho tecnico automatico
    [bus-box-technical-drawing.FCStd, bus-box-technical-drawing.dxf]
2026-06-01 feat: adicionar scripts para gerar imagens das pecas separadamente
    - generate-images.py: Exporta pecas como STEP e cria script de renderizacao
    - generate-images-mesh.py: Cria arquivos FCStd temporarios para cada peca
    - temp-Base.FCStd e temp-tampa.FCStd: Arquivos prontos para renderizacao
    - bus-box-parts-info.txt: Informacoes tecnicas das pecas
    [temp-Base.FCStd, temp-tampa.FCStd]
2026-06-03 refactor: reorganizar estrutura do projeto busbar
    - Criar pasta busbar/ para documentacao do sistema
    - Mover bus-box.FCStd para busbar/bus-box/
    - Renomear bus-box.md para busbar.md
    - Limpar arquivos temporarios, logs, scripts e cache
    - Atualizar .gitignore com padroes de ignorar
    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
    [bus-box-preview.stl, bus-box-technical-drawing.FCStd, bus-box-technical-drawing.dxf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]
2026-06-03 feat: atualizar modelo bus-box
    [bus-box.FCStd]
2026-06-03 docs: atualizar documentacao do sistema busbar com especificacoes tecnicas
    - Adicionar detalhes da barra de cobre (5x25mm, ~50mm)
    - Documentar parafusos inox M6 com porcas auto-travantes
    - Explicar escolha de materiais (inox, nylon)
    - Adicionar diagrama de funcionamento
    - Atualizar lista de materiais e status do projeto
2026-06-04 docs: adicionar documentacao completa do sistema de liga/desliga
    - Esquema eletrico com cores de fios
    - Diagrama de fiacao detalhado
    - Calculos eletricos (resistor de pre-carga)
    - Instrucoes de montagem passo a passo
    - Lista de compras com estimativa de precos
    - Procedimentos de teste e manutencao
2026-06-04 feat: atualizar modelo bus-box e adicionar pasta exports
    [bus-box-tampa.3mf, bus-box.FCStd]
2026-06-04 docs: reescrever sistema liga/desliga e atualizar baterias para 2 packs
2026-06-04 docs: adicionar fusíveis Spintend Physical Fuse v01 (2x 120A)
